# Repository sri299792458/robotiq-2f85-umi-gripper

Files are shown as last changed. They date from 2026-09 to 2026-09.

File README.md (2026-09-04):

# Robotiq 2F-85 UMI gripper

Prototype UMI-style soft gripper for the Robotiq 2F-85. Each jaw uses a rigid PETG adapter and a compliant TPU 95A gripper body based on the open UMI Fin-Ray-style architecture.

This is an independent experimental design. It is not supplied or endorsed by Robotiq and is not load-rated.

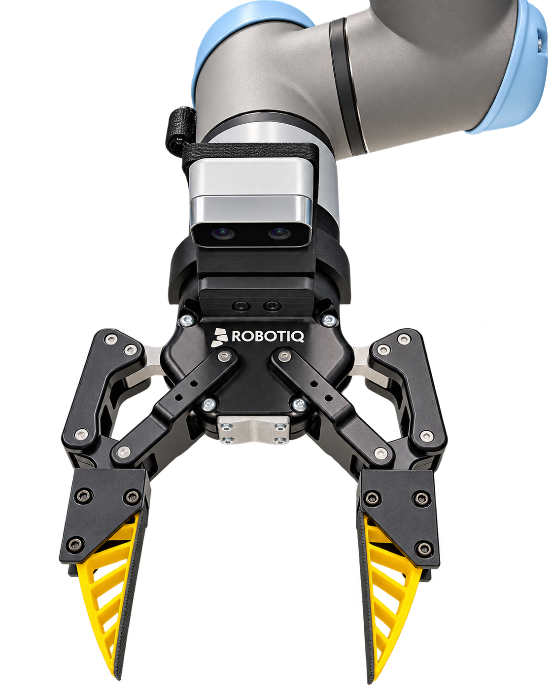
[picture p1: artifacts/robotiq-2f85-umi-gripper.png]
Robotiq 2F-85 with the UMI-style soft gripper


The photo above shows the initial physical prototype. The latest V2 revision below incorporates feedback from that print and awaits physical testing.

## Latest revision: V2

V2 reinforces the screw seats after the initial PETG adapter cracked during tightening. It uses shallow washer seats and uncut M3×30 screws, and brings the bare TPU rails into nominal contact at closure. Tape thickness is ignored for this revision.

- PETG adapter: 26.0 × 40.5 × 26.7 mm
- TPU finger: 15.48 × 74.019 × 23.990 mm
- TPU slot: 15.88 mm, providing 0.20 mm nominal clearance per side
- Three transverse M3 axes at `(Y,Z) = (13,5), (13,19.5), (34,19.5)` mm
- Washer seats: Ø7.5 × 0.6 mm, with 4.46 mm of PETG beneath them
- Captive-nut pockets: 6.3 mm across flats × 2.5 mm deep, with 2.56 mm of PETG beneath them
- Robotiq interface: Ø5.3 mm M5 clearance, 4 mm OEM-derived shoulder, Ø9.2 × 6 mm head/tool pocket, and two Ø2 × 2.5 mm indexing sockets
- Measured Ø8.5 × 4.9 mm M5 head has 1.1 mm axial clearance before the TPU seating face at Y=10 mm
- Closed gaps: 0 mm between bare TPU rails and 1 mm between PETG adapters
- M3×30 screw ends protrude approximately 4.1 mm beyond the PETG

The TPU body is derived from a direct 0.600-scale section of the UMI soft gripper. The original UMI internal cells are grouped into six larger through-bays while retaining the two-rail compliant load path. The PETG carrier is redesigned around the Robotiq removable-fingertip interface.

## V2 print files

Download the **[V2 print pack ZIP](artifacts/V2_PRINT_PACK_20260904.zip)**, or use the individual STLs:

| Part | Material | Copies |
| --- | --- | ---: |
| [Left adapter](artifacts/print_v2_20260904/V2_PETG_LEFT_PRINT_1.stl) | PETG | 1 |
| [Right adapter](artifacts/print_v2_20260904/V2_PETG_RIGHT_PRINT_1.stl) | PETG | 1 |
| [Finger](artifacts/print_v2_20260904/V2_TPU95A_FINGER_PRINT_2.stl) | TPU 95A | 2 |

All three files are already oriented for printing. Import in millimeters at 100% scale and place PETG and TPU on separate plates. PETG prints with the Robotiq mating face down, at 40.5 mm build height; TPU prints broad-side down, at 15.48 mm build height.

**Print all four parts.** The contact-side root hole moved, so the earlier TPU fingers do not match V2. For the pair, use six M3×30 socket-head screws, six M3 washers, and six M3 hex nuts, plus the existing Robotiq mounting hardware.

Washer dimensions remain provisional at 7 mm outside diameter × 0.5 mm thickness; the VIGRUE kit listing does not specify them. Check that the actual washers fit freely before tightening.

See the [print instructions](artifacts/print_v2_20260904/PRINT_README.md) and the existing [Bambu H2D / Overture TPU 95A profile](H2D_OVERTURE_TPU95A_PRINT_SETTINGS.md).

## Editable CAD and verification

- [Full closed-gripper Fusion fit check](artifacts/review_v2_20260904/REVIEW_V2_Robotiq_FITCHECK.f3d)
- [Standalone Fusion assembly](artifacts/review_v2_20260904/REVIEW_V2_ZeroGap_M3x30.f3d)
- [Standalone STEP assembly](artifacts/review_v2_20260904/REVIEW_V2_ZeroGap_M3x30.step)
- [Detailed V2 geometry, hardware assumptions, and QA](artifacts/review_v2_20260904/README.md)

The print meshes are watertight, consistently wound, and each contains one connected solid. All three washer seats and captive-nut pocket mouths are enclosed. Fusion checks found no positive-volume interference among the printed parts and nominal M3 hardware at closure.

Against the official closed Robotiq reference, the new hardware has at least 3.5347 mm clearance. The two previously recorded mounting-interface contacts remain, approximately 0.03682 mm³ per side. These checks cover nominal geometry at closure; they do not establish full-stroke clearance, tightening torque, fatigue life, or payload capacity.

## Rebuilding

Run [`scripts/build_finger_v2_review.py`](scripts/build_finger_v2_review.py) inside Autodesk Fusion, then [`scripts/inspect_finger_v2_review.py`](scripts/inspect_finger_v2_review.py). The generator uses the checked-in source section and writes to the V2 review directory. Its raw STLs retain assembly orientation; the separately supplied print pack contains the oriented versions.

The [V2 notes](artifacts/review_v2_20260904/README.md#reproduce) describe importing the official closed Robotiq reference and running the mechanism fit check. Additional reconstruction utilities are in [`scripts/`](scripts/); their Python dependencies are listed in [`requirements.txt`](requirements.txt).

## Earlier revision

The original STLs and `Skild_Inspired_2F85_Handed` CAD files directly under [`artifacts/`](artifacts/) are retained as the initial prototype. They use the earlier screw seats and 1.5 mm bare-TPU gap. Use the V2 print pack above for the current design.

## Prototype warning

Perform a low-force fit and closure test before carrying a payload. Verify mounting and washer seating, indexing-pin engagement, hardware clearance throughout motion, print tolerances, and TPU stiffness on the physical gripper.

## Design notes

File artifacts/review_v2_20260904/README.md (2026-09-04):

# V2 review: reinforced seats, zero bare-TPU gap, uncut M3x30 screws

This is a new review prototype built through Fusion MCP on 2026-09-04. The preceding production artifacts remain unchanged.

The user reported PETG cracking while tightening a root screw. Inspection of the preceding model found only 1.06 mm beneath each head recess and 0.96 mm beneath each nut pocket. The user requested nominal contact between the **bare TPU rails**, with tape thickness ignored, and confirmed that cutting/deburring screws is not available. V2 therefore uses unmodified M3x30 screws.

## Geometry

| Feature | V2 review |
|---|---:|
| Handed PETG adapter envelope, X/Y/Z | 26.0 / 40.5 / 26.7 mm |
| Root-down PETG print envelope | 26.0 / 26.7 / 40.5 mm |
| TPU envelope | 15.48 / 74.019 / 23.990 mm |
| TPU pocket | 15.88 mm, 0.20 mm nominal clearance per side |
| Washer seats | diameter 7.5 mm, depth 0.6 mm |
| Minimum PETG beneath washer seats | 4.46 mm |
| Captive-nut pockets | 6.3 mm across flats, depth 2.5 mm |
| Minimum PETG beneath nut pockets | 2.56 mm |
| PETG M3 / TPU M3 through-clearance | diameter 3.6 / 4.0 mm |
| Installed M3 axes, (Y,Z) | (13,5), (13,19.5), (34,19.5) mm |
| Bare TPU closed gap | 0.000 mm |
| Rigid PETG closed gap | 1.000 mm |
| Full M3x30 protrusion beyond PETG | 4.1 mm |
| Full M3x30 protrusion beyond nominal nut | 4.2 mm |

The accepted six-bay UMI section is translated 0.75 mm toward closure. The contact-side root hole then moves away from the closing edge, so the root-pair spacing is now 14.5 mm instead of 18 mm. The outer root hole and distal hole remain 21 mm apart longitudinally. The silhouette and all six bay polygons are otherwise retained. **New TPU prints are required.**

The Robotiq M5 axis, 4 mm shoulder, 6 mm head pocket, indexing sockets, and Y=10 mm TPU seating plane remain unchanged. The PETG side outline retains five straight edges. No compression sleeves or screw cutting are required for this review.

## Hardware basis and limits

Per jaw: three M3x30 socket-head screws, three M3 washers, and three M3 hex nuts. Reference hardware uses nominal 5.5 mm diameter x 3 mm screw heads and 5.5 mm-AF x 2.4 mm nuts. Threads are represented by clearance envelopes; the nominal nut is fully covered by the screw length.

**Washer size is provisional:** 7 mm outside diameter, 3.2 mm inside diameter, 0.5 mm thickness. The VIGRUE 1225-piece kit listing identifies M3 washers but does not publish their dimensions. Final washer fit therefore remains a physical check. The kit's material descriptions do not establish an allowable tightening torque for this printed joint.

All six screw tips point toward the same transverse side of the installed gripper. They do not project into the jaw closing gap, but remain exposed and can contact objects outside the modeled gripper.

## Verification

- `fusion_qa.json`: both printable bodies per jaw are solid; six bay profiles; all three complete TPU bores; complete PETG bores; all circular washer seats and hex pocket mouths enclosed; exact Robotiq M5/indexing cylinder dimensions; TPU seating at Y=10 mm.
- Fusion interference analysis of all 22 printable/reference hardware bodies returns no positive-volume intersections at mechanical closure. Measured gaps are 0 mm for TPU and 1 mm for PETG.
- `robotiq_fitcheck.json`: checked against the official closed Robotiq STEP with its four original fingertip/pad bodies excluded. All new M3 hardware clears the remaining mechanism, with a minimum distance of 3.5347 mm. The PETG shows the same pre-existing approximately 0.03682 mm3 contact per side at the OEM mounting interface; this is explicitly retained in the report rather than labeled zero overlap.
- `mesh_qa.json`: the two PETG and one TPU STL are watertight, consistently wound, and each one connected solid. Root-down transformations preserve mesh volume.

This verification covers rigid, nominal geometry in the closed configuration. It does not establish tightening torque, fatigue life, printed strength, or full-stroke/surrounding-workspace clearance. Physical fit and low-force closure remain to be checked on V2.

## Files

For slicing, use the [V2 print pack ZIP](../V2_PRINT_PACK_20260904.zip) or [print folder](../print_v2_20260904/PRINT_README.md). That pack contains only the three required STLs, already oriented for printing, with quantities and mesh checks. The assembly-oriented TPU export below requires rotation before slicing.

- `REVIEW_V2_Robotiq_FITCHECK.f3d`: editable full closed-gripper fit-check with nominal hardware.
- `REVIEW_V2_ZeroGap_M3x30.f3d` and `.step`: standalone finger pair and nominal hardware.
- `REVIEW_V2_nut_side.png`: exposed screw tips and captive nuts.
- `REVIEW_V2_head_side.png`: shallow washer seats and socket heads.
- `REVIEW_V2_on_Robotiq.png`: mounted closed-gripper review.
- `REVIEW_V2_2F85_PETG_Adapter_LEFT_M3_ROOT_DOWN_PRINT_1.stl`: one left PETG prototype.
- `REVIEW_V2_2F85_PETG_Adapter_RIGHT_M3_ROOT_DOWN_PRINT_1.stl`: one right PETG prototype.
- `REVIEW_V2_2F85_TPU95A_Finger_M3_PRINT_2.stl`: two identical new TPU prototypes, broad side down at 15.48 mm build height.

The other PETG STLs retain assembly orientation; use the ROOT_DOWN versions for slicing. Do not include any reference hardware in a printed-part export.

## Reproduce

Run `scripts/build_finger_v2_review.py` through Fusion MCP, then `scripts/inspect_finger_v2_review.py`. The copied `source_profile.json` preserves the exact source section used. The generator creates a new document and writes only to this review directory.

For the full mechanism check, import the official `2F-85_Closed.step` into that review, name the imported component `REFERENCE Robotiq closed mechanism`, and run `scripts/check_finger_v2_robotiq.py`. The script verifies the bounding boxes of the four excluded OEM fingertip bodies before excluding them.

Source listing: https://www.walmart.com/ip/503226562

Nominal washer dimensional reference: https://hi-line.com/m3-flat-washer-a2-stainless-steel/

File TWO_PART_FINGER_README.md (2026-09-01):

# Two-part finger technical summary

This document describes the current handed PETG adapter and identical TPU 95A soft-gripper body. For the repository overview and download links, see [`README.md`](README.md).

## Per-finger construction

- 1 × handed PETG adapter
- 1 × identical TPU 95A finger
- 1 × M5 × 0.8 × 12 mm socket-head cap screw for the Robotiq fingertip interface
- 3 × transverse M3 fasteners joining the PETG cheeks to the TPU tongue

Print one LEFT PETG adapter, one RIGHT PETG adapter, and two copies of the TPU finger.

## Current dimensions

- PETG adapter envelope: 22.8 × 40.5 × 27.2 mm
- Root-down PETG print envelope: 22.8 × 27.2 × 40.5 mm
- TPU finger envelope: 15.48 × 74.019 × 23.990 mm
- PETG tongue pocket: 15.88 mm
- TPU thickness: 15.48 mm
- Nominal pocket clearance: 0.20 mm per side
- Installed M3 centers `(Y,Z)`: `(13,2.25)`, `(13,20.25)`, `(34,20.25)` mm
- PETG M3 through-holes: Ø3.6 mm
- TPU M3 clearances: Ø4.0 mm
- M3 head recesses: Ø6.5 × 2.4 mm
- Captive-nut pockets: 6.3 mm across flats × 2.5 mm deep

## Robotiq interface

The removable-fingertip attachment retains the OEM-derived Ø5.3 mm M5 shank clearance and 4 mm shoulder. A Ø9.2 mm head/tool counterbore extends another 6 mm. With the measured 4.9 mm socket-head height, the bolt head ends at Y=8.9 mm and has 1.1 mm clearance before the TPU seating face at Y=10 mm.

Two Ø2 × 2.5 mm indexing sockets remain at X=±4.5 mm. The TPU has no M5-axis groove or relief.

## Finger architecture and closure

The TPU exterior is a direct 0.600-scale UMI soft-gripper section. Its three-hole triangle, exterior rails, and contact rail move as one architecture. Six larger through-bays replace groups of the original UMI cells.

The bare TPU rails retain a 1.5 mm total gap at mechanical closure, intended for approximately 0.75 mm grip tape on each contact face. The final Fusion checks report zero positive-volume intersection between PETG and TPU and between the opposed left/right parts.

## Production artifacts

- `artifacts/Robotiq_2F85_UMI_Handed.f3d`
- `artifacts/Robotiq_2F85_UMI_Handed.step`
- `artifacts/2F85_PETG_Adapter_LEFT_M3_ROOT_DOWN_PRINT_READY.stl`
- `artifacts/2F85_PETG_Adapter_RIGHT_M3_ROOT_DOWN_PRINT_READY.stl`
- `artifacts/2F85_TPU95A_Finger_M3_PRINT_2.stl`

This remains an unvalidated prototype. Begin with low-force fit and closure testing.

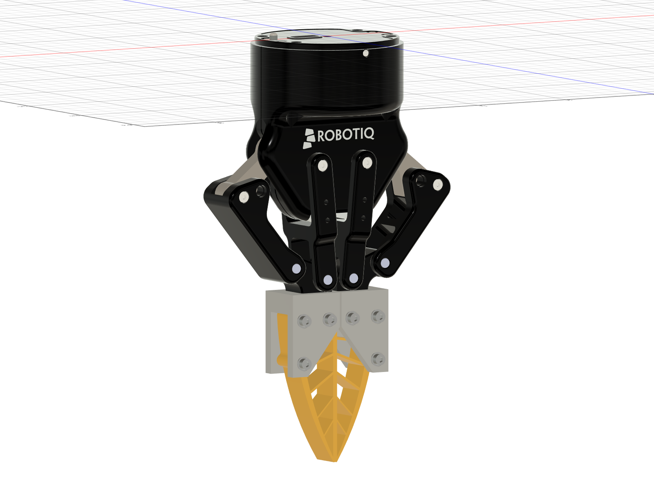
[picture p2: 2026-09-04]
artifacts/review_v2_20260904/REVIEW_V2_on_Robotiq.png

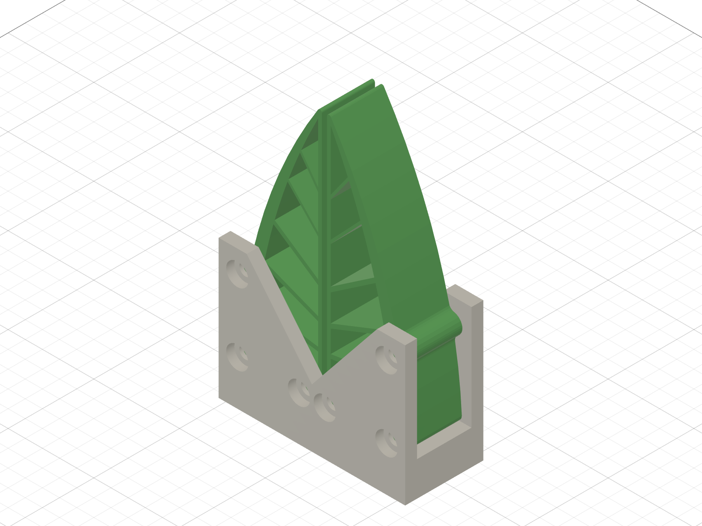
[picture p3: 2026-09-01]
artifacts/Robotiq_2F85_UMI_Handed_preview.png

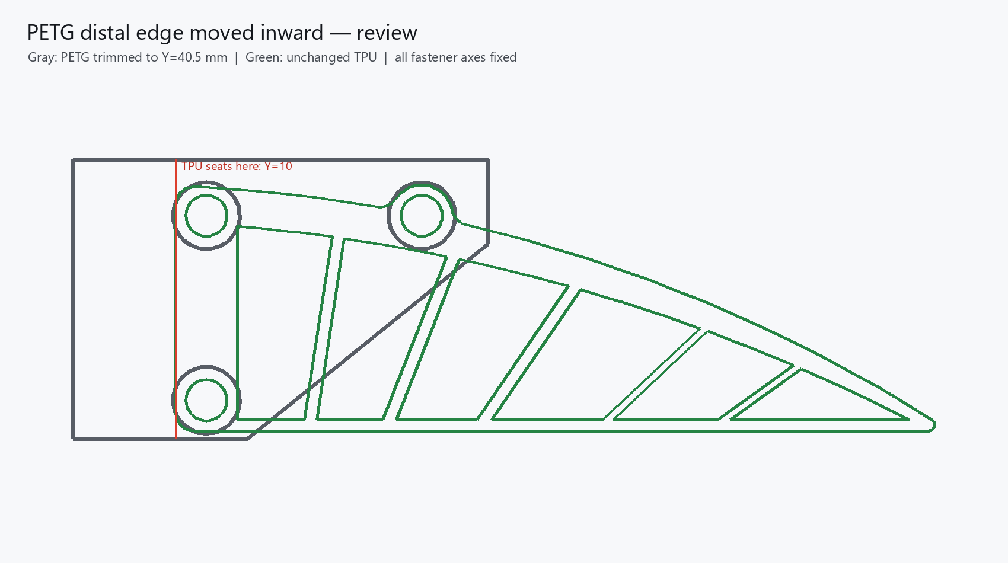
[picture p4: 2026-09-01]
artifacts/REVIEW_ONLY_PETG_distal_trim_review.png

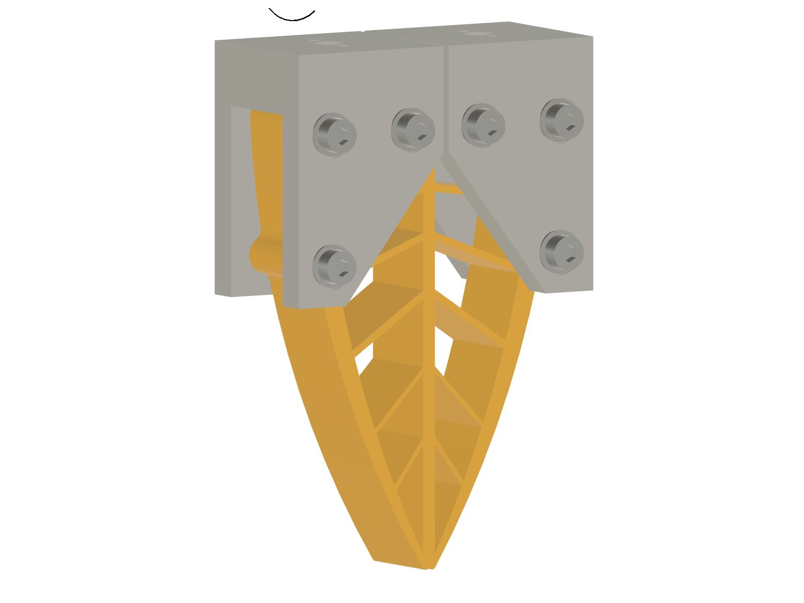
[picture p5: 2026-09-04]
artifacts/review_v2_20260904/REVIEW_V2_head_side.png

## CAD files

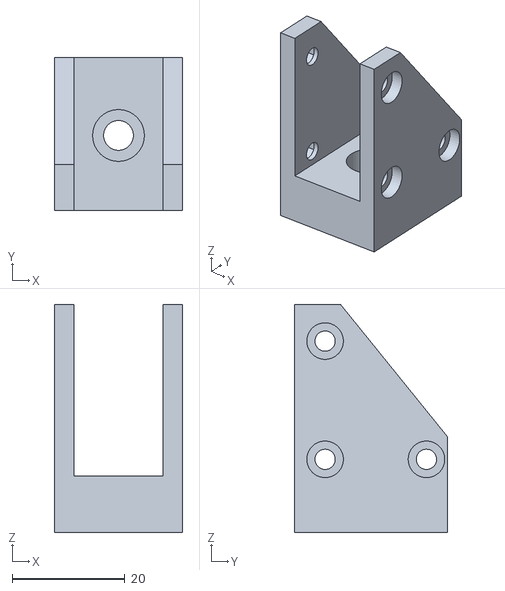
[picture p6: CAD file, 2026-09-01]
artifacts/2F85_PETG_Adapter_LEFT_M3_ROOT_DOWN_PRINT_READY.stl
22.8 x 27.2 x 40.5

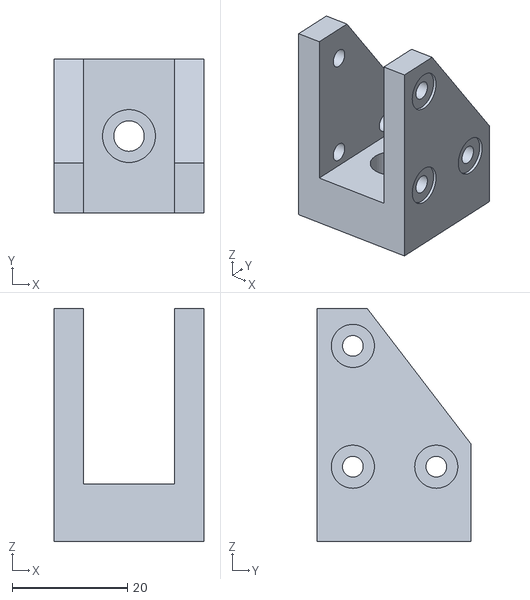
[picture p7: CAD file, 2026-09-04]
artifacts/print_v2_20260904/V2_PETG_LEFT_PRINT_1.stl
26.0 x 26.7 x 40.5

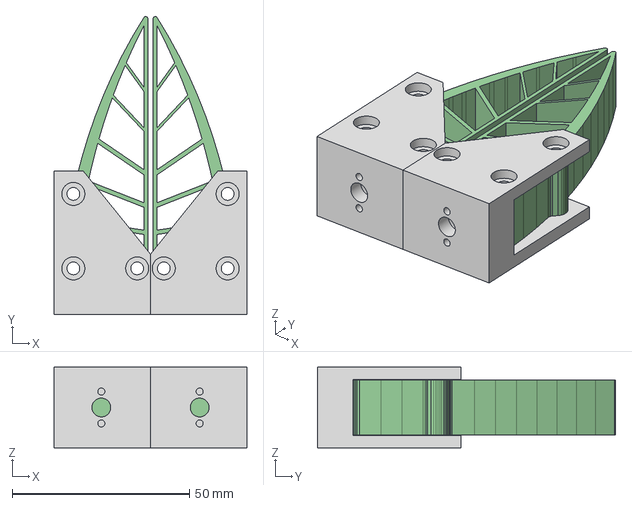
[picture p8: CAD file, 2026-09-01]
artifacts/Robotiq_2F85_UMI_Handed.step
54.4 x 84.0 x 22.8 mm

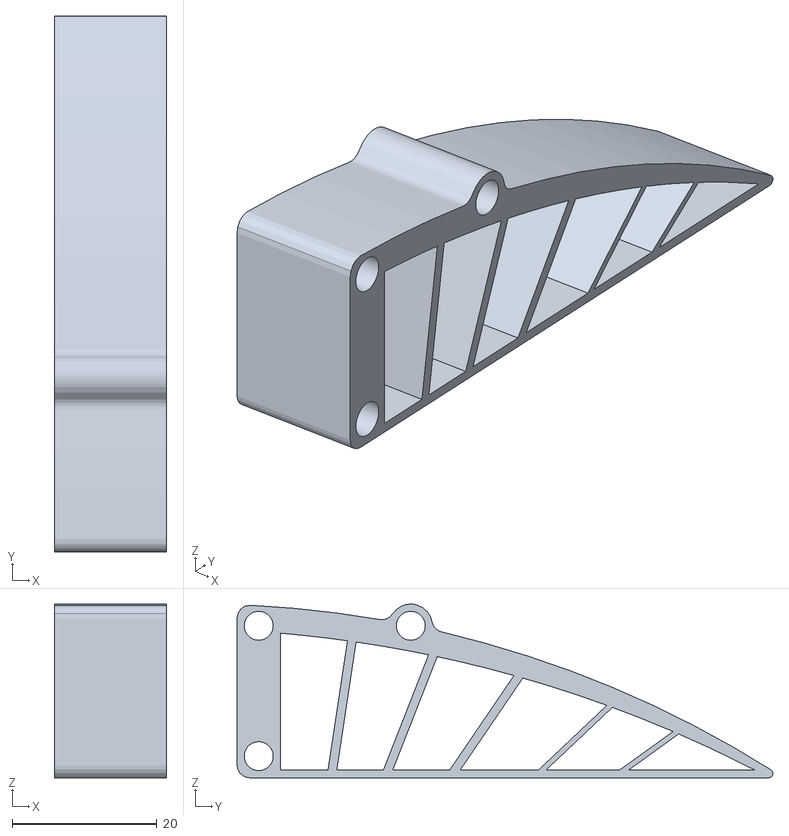
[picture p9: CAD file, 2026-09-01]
artifacts/2F85_TPU95A_Finger_M3_PRINT_2.stl
15.5 x 74.0 x 24.0

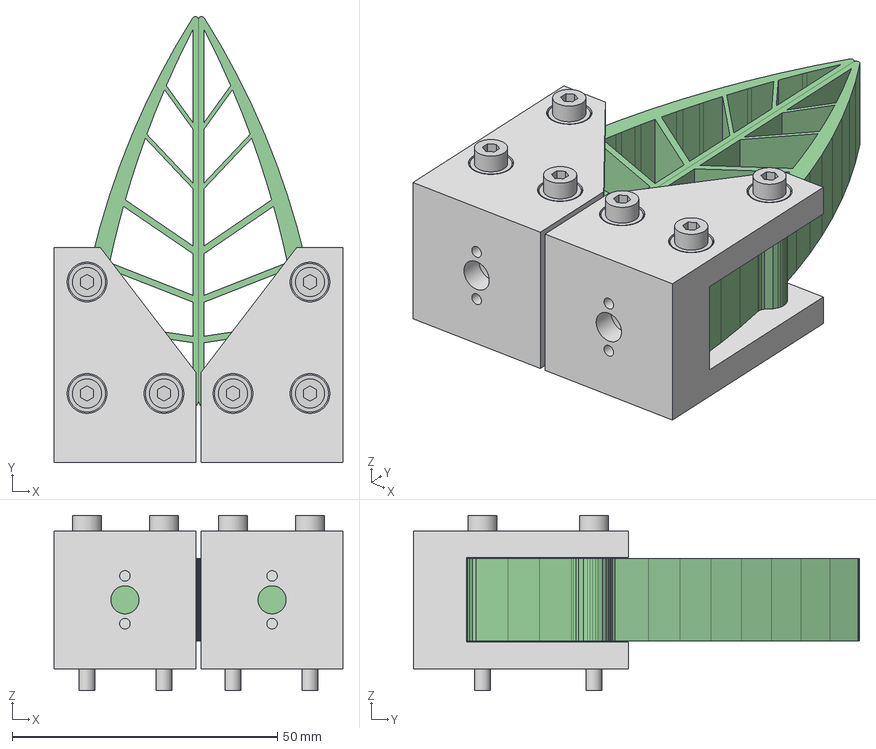
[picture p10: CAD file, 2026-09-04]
artifacts/review_v2_20260904/REVIEW_V2_ZeroGap_M3x30.step
54.4 x 84.0 x 33.0 mm

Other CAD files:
artifacts/review_v2_20260904/REVIEW_V2_2F85_PETG_Adapter_RIGHT_M3_PRINT_1.stl
artifacts/print_v2_20260904/V2_PETG_RIGHT_PRINT_1.stl
artifacts/review_v2_20260904/REVIEW_V2_2F85_PETG_Adapter_LEFT_M3_PRINT_1.stl
artifacts/print_v2_20260904/V2_TPU95A_FINGER_PRINT_2.stl
artifacts/2F85_PETG_Adapter_RIGHT_M3_ROOT_DOWN_PRINT_READY.stl
artifacts/review_v2_20260904/REVIEW_V2_2F85_PETG_Adapter_RIGHT_M3_ROOT_DOWN_PRINT_1.stl
artifacts/review_v2_20260904/REVIEW_V2_2F85_TPU95A_Finger_M3_PRINT_2.stl
artifacts/Robotiq_2F85_UMI_Handed.f3d
artifacts/review_v2_20260904/REVIEW_V2_Robotiq_FITCHECK.f3d
artifacts/review_v2_20260904/REVIEW_V2_ZeroGap_M3x30.f3d

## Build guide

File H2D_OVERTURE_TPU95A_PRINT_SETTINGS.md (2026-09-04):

# Bambu H2D — Overture TPU 95A finger profile

Use this existing material/process profile for [`V2_TPU95A_FINGER_PRINT_2.stl`](artifacts/print_v2_20260904/V2_TPU95A_FINGER_PRINT_2.stl). The V2 geometry still needs physical validation. This is regular Overture TPU 95A, not Overture High Speed TPU and not Bambu TPU for AMS.

## Filament preparation and feed

- Overture's forced-air specification is 70 °C for 7 hours. With the available AMS 2 Pro, use its maximum 65 °C for 12 hours as the lower-temperature equivalent.
- Put the spool on the AMS rollers but leave the filament end secured to the spool; do not insert this generic TPU into an AMS feeder funnel.
- On the H2D screen select `AMS Dry`, select the AMS 2 Pro, choose a manual/custom preset, set 65 °C and 12 h, close the lid, and start drying. Keep the AMS air intake and exhaust unobstructed.
- Use the H2D right hotend with the standard 0.4 mm nozzle.
- After drying, remove the spool and feed from the H2D external/bypass spool path. Do not route this filament through AMS 2 Pro.
- No active chamber heating. Keep the chamber below roughly 35 °C; crack the door if heat accumulates.

## Orientation

- The V2 print-pack STL is already broad-side down. For an assembly-orientation export, use **Lay on Face** on either large flat side of the finger.
- The six bays must face upward and the part must be 15.48 mm tall.
- The three M3 clearance holes must have vertical axes.
- Supports: off.
- Print one finger first for fit and stiffness validation; clone it only after that check.

## Filament profile

Start from `Generic TPU` and save a copy named `Overture TPU 95A — H2D 0.4`.

| Setting | Value |
|---|---:|
| Nozzle, first/other layers | 225 / 225 °C |
| Bed, first/other layers | 40 / 40 °C |
| Max volumetric speed | 3.2 mm³/s |
| Flow ratio | 1.00 |
| Retraction length | 0.4 mm |
| Cooling first two layers | 0% |
| Normal part cooling | 70% |
| Overhang/bridge cooling | 100% |
| Auxiliary fan | 0% |

If the extrusion looks intermittent or layers pull apart, use 230 °C. If the dry filament strings heavily, use 220 °C. Do not raise the volumetric limit until a separate flow test succeeds.

## Process profile

| Setting | Value |
|---|---:|
| Layer height / first layer | 0.20 / 0.20 mm |
| Wall generator | Arachne |
| Wall loops | 4 |
| Top / bottom shell layers | 5 / 5 |
| Sparse infill | 35% gyroid |
| First-layer speed | 20 mm/s |
| Outer wall | 25 mm/s |
| Inner wall | 35 mm/s |
| Sparse infill | 35 mm/s |
| Internal solid infill | 30 mm/s |
| Top surface | 25 mm/s |
| Bridges | 20 mm/s |
| Supports | Off |
| Ironing | Off |

- Enable `Avoid crossing walls`.
- Paint the seam onto the non-contact outer rail. Do not use random seam placement and keep the seam off the narrow TPU contact rail.
- Use a thin layer of liquid glue as a release layer on smooth or textured PEI. Do not use the SuperTack plate for this print.
- No brim should be needed with the broad-side-down orientation. Add a 3 mm outer brim only if the first prototype lifts.

## Before pressing Print

1. Confirm the slicer shows an approximately 74.019 × 23.990 mm footprint and 15.48 mm height.
2. Inspect the first-layer preview: all six bay openings must remain open.
3. Confirm support material is zero.
4. Confirm the right nozzle is assigned and the filament is coming from the external/bypass path.
5. Watch the first three layers for clean extrusion and adhesion.

After cooling, flex the plate and peel the part slowly. Clear the three Ø4.0 mm holes by hand if necessary; do not drive the bolts through undersized or string-filled holes.

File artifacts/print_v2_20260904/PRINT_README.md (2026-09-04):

# V2 gripper print pack - 2026-09-04

This pack contains the updated zero-gap design with reinforced washer seats and uncut M3x30 screws.

## Print quantities

| STL | Material | Copies | Build size X x Y x Z (mm) |
| --- | --- | ---: | --- |
| V2_PETG_LEFT_PRINT_1.stl | PETG | 1 | 26.0 x 26.7 x 40.5 |
| V2_PETG_RIGHT_PRINT_1.stl | PETG | 1 | 26.0 x 26.7 x 40.5 |
| V2_TPU95A_FINGER_PRINT_2.stl | TPU 95A | 2 | 74.019 x 23.990 x 15.48 |

Four physical parts total. The TPU STL contains one finger; duplicate it once in the slicer.

## Slicer setup

- Import as millimeters at 100% scale. All STLs are already oriented for printing.
- PETG: Robotiq mating face down; finished build height 40.5 mm. Retain this orientation instead of laying the adapter on a cheek face.
- TPU: broad side down; six bays open upward; M3 hole axes vertical; finished build height 15.48 mm. Supports off for TPU.
- Put PETG and TPU on separate plates and use the material/process profiles from the previous print.
- This pack contains geometry, not printer-specific sliced G-code.

## Assembly notes

- Print both updated TPU fingers: the contact-side root hole moved, so the preceding TPU parts do not match this revision.
- For the pair: six M3x30 socket-head screws, six M3 washers and six M3 hex nuts. Retain the existing Robotiq mounting hardware.
- Washer seats are 7.5 mm diameter. Reference washer dimensions are provisionally 7 mm OD x 0.5 mm thick; check the actual kit washers fit freely before tightening.
- Nominal closure: bare TPU rails touch; PETG adapters retain a 1 mm gap. Tape thickness is ignored as requested.
- Screw ends project about 4.1 mm past the PETG. No screw cutting is required.

The meshes have been checked for watertightness, connected solids, dimensions and orientation. V2 remains a prototype awaiting physical fit and low-force closure checks; the CAD mechanism check covered the closed configuration.

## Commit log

2026-09-01 Initial public release
    [2F85_PETG_Adapter_LEFT_M3_ROOT_DOWN_PRINT_READY.stl, 2F85_PETG_Adapter_RIGHT_M3_ROOT_DOWN_PRINT_READY.stl, 2F85_TPU95A_Finger_M3_PRINT_2.stl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]
2026-09-04 Add reinforced zero-gap V2 gripper and print pack
    [REVIEW_V2_2F85_PETG_Adapter_LEFT_M3_PRINT_1.stl, REVIEW_V2_2F85_PETG_Adapter_LEFT_M3_ROOT_DOWN_PRINT_1.stl, REVIEW_V2_2F85_PETG_Adapter_RIGHT_M3_PRINT_1.stl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]
